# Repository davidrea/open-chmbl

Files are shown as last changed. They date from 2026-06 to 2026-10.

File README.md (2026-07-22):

# open-chmbl

In automotive engineering, the CHMBL is the "Center High-Mounted Brake Light" — this
repository is an **"Open-sourCe Helmet Mounted Brake Light"** for motorcyclists.

A battery-powered ~8″ LED bar worn on the rider's back — magnetically clamped to a
jacket or backpack — lights up when the motorcycle is braking. The reference bike
doesn't publish a brake-switch bit on its **CAN bus**, so braking is **inferred from
wheel-speed deceleration** read off the bus (via the Euro 5 diagnostic port,
**listen-only**) and sent wirelessly to the rider-side unit over **ESP-NOW**. Clutch
and gear/neutral context lets it hold the light through a stop and release it sensibly
when the bike pulls away — deriving deceleration from the bike's own CAN wheel-speed
(not an accelerometer) keeps it clear of the inertial-detection patents.

Two units, both ESP32-based:

- **[`transmitter/`](transmitter)** — bike-side; plugs into the diagnostic port,
  decodes CAN, broadcasts braking state.
- **[`brake_light/`](brake_light)** — rider-side; battery-powered LED bar (fabric
  mount this rev; helmet fitment deferred) that renders the state.

> ⚠️ Auxiliary device. It does **not** replace the bike's factory brake light, and
> helmet-mounted lighting is restricted in some places. Read
> **[`docs/safety-regulatory.md`](docs/safety-regulatory.md)** before building or
> riding.

## Start here

- **[`ARCHITECTURE.md`](ARCHITECTURE.md)** — system overview and design index.
- **[`docs/feature-functions.md`](docs/feature-functions.md)** — per-device capabilities.
- **[`docs/design/README.md`](docs/design/README.md)** — how we build it: design
  elements, implemented one at a time in isolation.
- [`docs/cli.md`](docs/cli.md) · [`docs/hardware.md`](docs/hardware.md) ·
  [`docs/firmware.md`](docs/firmware.md) · [`docs/protocol.md`](docs/protocol.md) ·
  [`docs/can-profiles.md`](docs/can-profiles.md) ·
  [`docs/safety-regulatory.md`](docs/safety-regulatory.md) ·
  [`docs/roadmap.md`](docs/roadmap.md)

Status: **architecture / design phase** (see the roadmap).

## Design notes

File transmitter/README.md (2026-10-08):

# Transmitter (bike-side)

Plugs into the motorcycle's diagnostic port, reads the CAN bus **listen-only**,
decodes brake/throttle/RPM/clutch via the active [bike profile](../docs/can-profiles.md),
runs the [braking state machine](../docs/firmware.md#braking-state-machine), and
broadcasts state to the [`brake_light`](../brake_light) over
[ESP-NOW](../docs/protocol.md).

- [`hardware/`](hardware) — reuses the [`logger/`](../logger) PCB (ESP32-S3); see
  [`hardware/README.md`](hardware/README.md) for pinout and BOM notes.
- [`software/`](software) — ESP32-S3 firmware for that board: TWAI listen-only,
  profile decode, the [braking state machine](../docs/design/de-09-brake-decel-logic.md)
  driving the light, and ESP-NOW TX. See
  [`software/README.md`](software/README.md).

See [`ARCHITECTURE.md`](../ARCHITECTURE.md) for the big picture and
[`docs/hardware.md`](../docs/hardware.md) for the parts sketch.

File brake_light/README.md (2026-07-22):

# Brake_light (rider-side)

Battery-powered ~8″ wide red LED bar worn on the rider's back — magnetically clamped
to a jacket or the top of a backpack between the shoulder blades (a steel strip or
washers inside the garment / pack completes the mount). Receives braking state from
the [`transmitter`](../transmitter) over [ESP-NOW](../docs/protocol.md) and renders
it on the bar with ambient-aware brightness, while managing its own 1S 18650 Li-ion
battery, USB-C charging, pairing, and [link-loss failsafe](../docs/protocol.md#4-failsafe--link-health).

Helmet fitment is **deferred** — the current form factor targets a thin, short-in-
the-vertical-axis, wide fabric-mounted bar so shell curvature and helmet-certification
questions don't gate the first build.

- [`hardware/`](hardware) — LED bar, 18650 + charging (chip-down), enclosure,
  magnetic fabric mount.
- [`software/`](software) — ESP32-C3 firmware (ESP-NOW RX + LED pattern engine).

⚠️ Mounting and battery safety are not optional — see
[`docs/safety-regulatory.md`](../docs/safety-regulatory.md). See
[`ARCHITECTURE.md`](../ARCHITECTURE.md) for the big picture.

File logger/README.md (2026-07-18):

# logger

A self-contained **CAN data logger** on a **custom ESP32-S3 PCB** with an onboard CAN
transceiver. It captures **all** bus traffic (no filtering) in **listen-only** mode
and writes it to the on-board microSD as **PCAN `.trc`** ASCII files that drop
straight into the project's offline decode/replay path (`python-can` + `cantools`,
see [`docs/can-profiles.md`](../docs/can-profiles.md)).

This is the **ride-logging rig** for design element
[**DE-07**](../docs/design/README.md) — a no-Linux ESP32 alternative to the Raspberry
Pi originally sketched for capturing wheel-speed and other in-motion signals. The
stationary bench captures are done separately with PCAN-USB + a laptop.

This board is also the base design the [`transmitter/`](../transmitter) reuses
(same PCB, connectors for the microSD and button/LED removed) — see
[`hardware/README.md §4`](hardware/README.md#4-shared-design-with-the-transmitter).

- [`hardware/`](hardware) — the custom ESP32-S3 PCB: schematics, connectors, power,
  and a known strapping-pin issue to check before relying on a board. See
  [`hardware/README.md`](hardware/README.md).
- [`software/`](software) — ESP-IDF firmware. **Currently still targets the retired
  ESP-WROVER-KIT bring-up hardware (`esp32`)**, not yet ported to the custom board
  above — see the status note in [`software/README.md`](software/README.md). Pins,
  wiring, the `.trc` format, and build/flash steps for the current target are
  documented there.

> Listen-only by default — the logger never ACKs or transmits, per the repo's
> [golden rule](../docs/can-profiles.md#1-golden-rule-listen-only). Power-loss and
> card-removal robustness are intentionally out of scope.

## Visualizing a log

Open [`tools/trc_viz.html`](../tools/trc_viz.html) directly in any modern browser,
then drag a logger `.trc` file onto the page (or use **Open trace**). It is one local
HTML file with no server, install, or network access required. The viewer decodes the
Triumph TR profile in-browser and provides live playback gauges, a zoomable timeline,
nearby raw-frame inspection, and live [DE-09 brake FSM](../docs/design/de-09-brake-decel-logic.md)
tuning. It does not upload or retain the trace.

For automated decode comparisons and the older native dashboard, the Python tools
remain available:

```sh
uv run tools/trc_viz.py logger/40mph_drive_cycle.trc --headless-check
```

[uv]: https://docs.astral.sh/uv/

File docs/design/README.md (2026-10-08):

# Design documents

How we get from capabilities to code: **feature-function lists → design documents →
isolated implementation → integration.** We deliberately avoid formal shall-statement
requirements; the [feature-function lists](../feature-functions.md) are the
capability baseline, and each **design element** below is a self-contained slice we
design and build **one at a time, in isolation**, exercised through the
[developer CLI](../cli.md).

---

## 1. Process

1. **Capabilities** live in [`feature-functions.md`](../feature-functions.md) (FFL IDs).
2. **Design elements** (this directory) each take a small set of FFL IDs and work them
   into a buildable design: components, I/O, firmware tasks, and the CLI hooks that let
   us test the element alone.
3. **Implement one element at a time.** Inputs at the element's boundary are **faked**
   via the CLI; outputs are **viewed** via the CLI. The element is "done" when its FFL
   IDs are demonstrable in isolation.
4. **Integrate** elements once each is independently proven.

Cross-cutting design context already in progress lives one level up:
[`hardware.md`](../hardware.md), [`firmware.md`](../firmware.md),
[`protocol.md`](../protocol.md), [`can-profiles.md`](../can-profiles.md), and the
[`led-brightness-benchmark.md`](../led-brightness-benchmark.md) sizing study (feeds DE-04
and DE-02). Design elements here reference those rather than repeating them.

---

## 2. Design-document template

Every `de-*.md` follows this structure:

1. **Scope & isolation boundary** — what's in, what's out, and *what is faked at the
   edges* to test it alone.
2. **FFL traceability** — the [feature-function](../feature-functions.md) IDs this
   element realizes.
3. **Component selection** — hardware parts and/or software libraries this element
   depends on, with rationale (defer to [`hardware.md`](../hardware.md) for shared parts).
4. **I/O assignments & configuration** — pins, peripherals, registers, bit rates,
   timings, message layouts.
5. **Firmware module/task decomposition** — tasks, queues, shared state, rates,
   ownership; the pure (host-testable) vs. platform parts.
6. **CLI hooks** — the [CLI](../cli.md) commands used to fake inputs / view outputs for
   isolation testing.
7. **Isolation acceptance** — what we demonstrate, via the CLI, to call it done.
8. **Open items.**

---

## 3. Design elements (build order)

Ordered by dependency and the agreed sequence (CLI first so everything else is
testable in isolation; CAN-dependent elements last, after captures exist). Status:
🔲 not started · 🟡 in design · 🟢 implemented.

| ID | Element | Device(s) | Realizes (FFL) | Depends on | Status |
|----|---|---|---|---|---|
| **DE-00** | [CLI / shell framework](../cli.md) | both | TX-CLI-*, BL-CLI-* | — | 🟡 |
| **DE-01** | [ESP-NOW link](de-01-espnow-link.md) | both | TX-NET-*, BL-NET-* | DE-00 | 🟢 |
| **DE-02** | [Auto-brightness](de-02-auto-brightness.md) | brake_light | BL-BRT-* | DE-00 | 🔲 |
| **DE-03** | [Link-loss failsafe](de-03-link-loss-failsafe.md) | brake_light | BL-FS-* | DE-00, DE-01 | 🟡 |
| **DE-04** | [LED render & bar driver](de-04-led-render.md) | brake_light | BL-RND-*, BL-LED-* | DE-00 | 🟡 |
| **DE-05** | Battery & charge management | brake_light | BL-PWR-* | DE-00 | 🔲 |
| **DE-06** | TX power / sleep / wake | transmitter | TX-PWR-* | DE-00 | 🔲 |
| **DE-07** | CAN capture & offline analysis — bench (PCAN-USB) + [ride logger](../../logger/) (custom ESP32-S3 PCB) | host + [`logger/`](../../logger/) | (enables TX-DEC) | — | 🟡 |
| **DE-08** | [Embedded CAN decode](de-08-can-decode.md) | transmitter | TX-CAN-*, TX-DEC-* | DE-00, DE-07 | 🔲 |
| **DE-09** | [Braking state machine](de-09-brake-decel-logic.md) | transmitter | TX-SM-* | DE-00, DE-08 | 🟢 |
| **DE-10** | [Status-indicator LED](de-10-status-indicator.md) | brake_light | BL-IND-* | DE-00 | 🔲 |

DE-05…DE-06 don't have stub docs yet; they get one when scheduled. DE-07 is the
bench/ride reverse-engineering captured in [`can-profiles.md`](../can-profiles.md); the
**ride-logging half is now a real device** — a self-contained logger under
[`logger/`](../../logger/) (firmware implemented, now with a
[custom ESP32-S3 PCB](../../logger/hardware/README.md) — firmware port from the
original ESP-WROVER-KIT bring-up hardware pending) that replaces the Raspberry Pi
rig, while the stationary bench captures stay on PCAN-USB + a laptop.

This table is the single source of truth for "what's the next isolated piece."

---

## 4. Future-state explorations

Directions we want on record but have **not** committed to the build order above.
They live in [`explorations/`](explorations/README.md) and get promoted to a
`de-*` element (with FFL traceability and an isolation test) only when scheduled:

- [Magnetic mounting](explorations/mounting-magnetic.md) — garment/backpack shoulder
  mount and interchangeable VHB-on-helmet steel targets, both using magnets for a
  built-in shear release.

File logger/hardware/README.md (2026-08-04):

# Logger — hardware

Custom PCB (KiCad, [`logger.kicad_pro`](logger.kicad_pro)) that replaced the original
ESP-WROVER-KIT bring-up rig. Self-powered from the bike's 12 V or from USB-C, decodes
nothing on-board — it just timestamps and records **all** CAN traffic to a microSD card.
See [`../README.md`](../README.md) for the device-level description and
[`../software/README.md`](../software/README.md) for firmware status.

This board is also the **base design for the [`transmitter/`](../../transmitter)**
bike-side unit — see [§4](#4-shared-design-with-the-transmitter).

## 1. MCU: ESP32-S3-WROOM-1-N4

**ESP32-S3**, not the ESP32-C3 used elsewhere in this project (`brake_light/`, and
the transmitter's earlier sketch — see [`docs/hardware.md`](../../docs/hardware.md)).
The reason is the **microSD interface**: this design uses the SoC's native **SDMMC
host peripheral** (full 4-bit bus — `CLK`/`CMD`/`DAT0`–`DAT3`, see §3.4) for the
throughput a listen-only, no-filtering CAN capture needs. **The ESP32-C3 doesn't have
an SDMMC host peripheral** — only SPI — so it was not an option for this board. The
C3 stays the right choice for `brake_light/`, which has no SD card.

`-N4` = 4 MB flash, **no PSRAM**. (The retired ESP-WROVER-KIT target had 4 MB of
PSRAM the firmware currently depends on — `CONFIG_SPIRAM=y` — see the note in
[`../software/README.md`](../software/README.md).)

## 2. Power

```
 J3 pin 3 (+12 V, bike) ──▶ D4 (Schottky, reverse-pol.) ─┐
                                                          ├─▶ +5VD rail ─▶ U4 (TPS62172
 J2 (USB-C VBUS, 5 V)   ──▶ U3 (USBLC6-2P6 ESD) ─────────┘              buck) ─▶ +3V3
```

- **D4** (`20CJQ060`, Schottky) diode-ORs the bike's 12 V input against USB-C VBUS
  onto a shared **+5VD** rail, so the board can be bench-powered/flashed over USB-C
  without the bike connected, and the diode blocks backfeed onto the bike harness.
- **U4** (`TPS62172`, buck) steps +5VD down to **+3V3**, which powers the ESP32-S3,
  the CAN transceiver, and the microSD card.
- **D3** (`SM24CANB-02HTG`, dual TVS) sits right at J3 protecting CAN-H/CAN-L from
  bus transients.

There is no automotive load-dump-rated buck or a dedicated reverse-polarity FET here
(that was the original `docs/hardware.md` sketch) — this rev uses a Schottky diode for
reverse-polarity protection and a standard (not automotive-grade) buck. Revisit before
this board goes on a bike full-time; fine for bench/ride-logging use.

## 3. Connectors

| Ref | Type | Function |
|-----|---|---|
| **J2** | USB-C receptacle | Power, flash, and console. **Native USB** — D+/D- wired directly to the ESP32-S3 (no USB-UART bridge chip). CC1/CC2 have 5.1 kΩ pull-downs (UFP power-sink detection). ESD-protected by U3 (`USBLC6-2P6`). |
| **J3** | JST-PH, 5-pin | Bike harness. Pin 1 **CAN-L**, pin 2 **CAN-H**, pin 3 **+12 V**, pin 4 **GND**, pin 5 **spare/unconnected**. TVS-protected at the connector (D3). |
| **J4** | JST-PH, 4-pin | Button/LED breakout. Pin 1 **GND**, pin 2 **LED drive** (through Q1, a low-side `2N7002K` switch), pin 3 **button input** (`BTN_SIG`, pulled up to 3V3, active-low), pin 4 **+3V3**. Both signal pins are TVS-protected (D1/D2, `PTVS3V3D1BALYL`) since this connector feeds an external panel-mount switch/LED on flying leads. |
| **J5** | microSD (Molex 104031-0811) | Full SDMMC **4-bit** bus (`CLK`, `CMD`, `DAT0`–`DAT3`) + card-detect (`DET_A`, pulled up) + 3V3/GND, wired straight to the ESP32-S3's SDMMC host peripheral. |

### 3.1 CAN transceiver

**U2 (`TCAN330`)**, 3.3 V logic — TXD/RXD to the ESP32-S3, plus its **silent-mode
(`S`) pin** wired to a GPIO so firmware can force RX-only operation in hardware, not
just in software. This pin was moved to a non-strapping GPIO to fix an earlier
strapping-pin conflict — see [§5](#5-resolved--can-silent-pin-moved-off-strapping-pin-gpio45).

### 3.2 microSD (J5)

Sized for a real ride-logging device: full 4-bit SDMMC, not the slower 1-bit/SPI
fallback. This is the peripheral that dictated the ESP32-S3 (§1).

### 3.3 Button/LED (J4)

Optional external start/stop button + status LED on flying leads (the onboard `SW1`/
`SW2` push-button footprints are DNI placeholders for a bench BOOT/EN header, not the
operator control). `Q1` (`2N7002K`) is a low-side switch for driving an LED through
J4 pin 2; `R4` is the current-limit resistor.

## 4. Shared design with the transmitter

The `transmitter/` bike-side unit reuses this exact board with **J4** (button/LED)
and **J5** (microSD) left unpopulated — the transmitter needs neither a card slot nor
a physical button/LED breakout. See
[`transmitter/hardware/README.md`](../../transmitter/hardware/README.md) and
[`docs/hardware.md §1`](../../docs/hardware.md#1-transmitter-bike-side).

## 5. Resolved — CAN silent pin moved off strapping pin (`GPIO45`)

An earlier rev routed the CAN transceiver's silent-mode pin (`U2` pin 8) to
**`GPIO45`**, one of the ESP32-S3's strapping pins — it selects the SPI-flash/PSRAM
supply voltage at reset (low = internal 3.3 V regulator, correct for this module;
high = expects an externally-supplied 1.8 V rail). **`R16`** pulls the `S` pin up to
3V3 to default the transceiver to **silent mode before firmware runs** (the right
failsafe for a listen-only device), but with `S` on `GPIO45` that pull-up also drove
the strapping pin high at boot — the same class of bug already hit once on this
project's bench boards (GPIO8 vs. the SPI-flash bus — see the blink-LED note) and a
known cause of ESP32-S3 boards that won't boot / report flash read errors.

**This is fixed in the current schematic:** the `S` pin is now on **`GPIO35`** (a
non-strapping GPIO, free on the `-N4` module since it has no PSRAM), and `R16` pulls
`GPIO35` up — keeping the default-silent failsafe without touching any strap.
`GPIO45` is left **unconnected**, so its internal pull-down selects the 3.3 V flash
supply as intended. The two other straps are clean too: `IO0` is the boot button
(internal pull-up) and `GPIO46` is unconnected. Still worth a bring-up confirmation
that `GPIO45` is unstuffed and boot is repeatable — see
[`BRINGUP.md §4`](BRINGUP.md#4-gpio--strapping-verification).

## 6. Fabrication / BOM

KiCad project only — `bom.csv`, `positions.csv`, `netlist.ipc`, and the JLC
export zip under `production/` are regenerated locally by the KiCad Fabrication
Toolkit plugin and are **gitignored**, not committed. Re-export from
[`logger.kicad_pcb`](logger.kicad_pcb) / [`logger.kicad_sch`](logger.kicad_sch) as
needed.

Key parts: `U1` ESP32-S3-WROOM-1-N4, `U2` TCAN330, `U4` TPS62172, `U3` USBLC6-2P6,
`D3` SM24CANB-02HTG, `D4` 20CJQ060.

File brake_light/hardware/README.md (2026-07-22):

# Brake_light — hardware

Rider-side electronics. See [`docs/hardware.md §2`](../../docs/hardware.md#2-brake_light-rider-side)
for the block diagram and parts sketch.

Key constraints:
- **Bare ESP32-C3 module** (ESP32-C3-WROOM-02 baseline) + **chip-down** LiIon
  charger, DC-DC, and LED driver. Moved off the integrated dev-board path (previously
  scoped in the removed `§2.1` module survey) to unlock the thin/wide form factor
  below — see [`docs/hardware.md §2.1`](../../docs/hardware.md#21-parts-direction-bare-module--chip-down).
- **~8″ wide red LED bar** (620–630 nm mid-power) driven from a boost constant-current
  driver (TI **LM3410** baseline; upgrade parts noted in de-04). One series string of
  ~8 emitters — split into parallel strings if the emitter count outruns the driver's
  V<sub>out</sub> ceiling. Series-string + boost topology set in
  [`docs/design/de-04`](../../docs/design/de-04-led-render.md).
- **Ambient-light auto-dimming** (safety requirement — no blinding at night).
- **Status-indicator LED** — **discrete WS2812B** (2020 / Mini) chip-down, **separate
  from the bar** — for status/fault by color + blink code
  ([`docs/design/de-10`](../../docs/design/de-10-status-indicator.md)). No longer
  free-riding on a module's onboard RGB (we're on a bare module now).
- **Battery: 1S 18650 Li-ion, protected cell** + USB-C charging with **load sharing**
  (MCP73871 chip-down baseline). 18650 chosen over pouch/LiPo because pouch cells
  need mechanical compression the thin enclosure can't provide; protected cell means
  the load-share IC doesn't have to double as cell protection.
- **Form factor: thin, short-in-vertical (viewed from the rear), wide.** The ~8″ LED
  bar sets the width; the 18650's ~18 mm diameter sets the enclosure-thickness floor.
- **Mount: magnetic to jacket / backpack fabric.** Magnets live in the light
  assembly; a thin steel strip or washers sit inside the garment or pack so the
  fabric is sandwiched between them. This is the [garment / backpack shoulder
  mount](../../docs/design/explorations/mounting-magnetic.md#exploration-a--garment--backpack-shoulder-mount)
  exploration promoted to the current baseline; helmet fitment and cross-form
  interchangeability are **deferred**.
- Sized for a full-day runtime target — with a ~3000 mAh 18650 the runtime budget
  roughly doubles the earlier 1500 mAh LiPo worked example (see hardware doc).
- Sealed, IP65+ enclosure.

⚠️ Mounting + Li-ion safety are mandatory reading: [`docs/safety-regulatory.md`](../../docs/safety-regulatory.md).

_Schematics, BOM, enclosure, and mount files to be added (Phase 4)._

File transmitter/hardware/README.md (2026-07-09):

# Transmitter — hardware

Bike-side electronics. See [`docs/hardware.md §1`](../../docs/hardware.md#1-transmitter-bike-side)
for the block diagram and parts sketch.

**Hardware plan: this board is the [`logger/`](../../logger) PCB**, reused with the
microSD slot (J5) and button/LED breakout (J4) left unpopulated — the transmitter
needs neither. No separate transmitter schematic exists; the logger's is the source
of truth. See [`logger/hardware/README.md`](../../logger/hardware/README.md) for the
schematic, connector pinout (J2 USB-C, J3 bike harness), and BOM notes, and
**[§5 there](../../logger/hardware/README.md#5-known-issue--gpio45s-pin-conflicts-with-a-boot-strap)**
for an open strapping-pin issue to check before building a board off this design.

As reused:
- **ESP32-S3-WROOM-1** + **TCAN330** CAN transceiver (3.3 V), silent-mode pin wired
  to a GPIO for a hardware-level listen-only default.
- Diode-ORed 12 V (bike) / USB-C VBUS power into a TPS62172 buck (12 V → 3.3 V).
  **Not** automotive load-dump-rated in this rev — reverse-polarity protection is a
  Schottky diode, not a FET; revisit before full-time bike use.
- **Listen-only** CAN — never ACK or transmit on the bus.
- J3 (bike-side connector, JST-PH 5-pin): CAN-L, CAN-H, +12 V, GND, spare.

Not yet on this board (deltas from the shared logger design, tracked for Phase 4):
- Deep-sleep / load-shed when the bike is off (< 1 mA parked) — needs an ignition
  sense the logger board doesn't have.
- Sealed, IP65+, vibration- and heat-tolerant enclosure.

Reference bike connector ([Triumph Speed 400 / Scrambler 400 X / Street Triple 765](../../docs/can-profiles.md#5-reference-target--triumph-speed-400-tr-series-platform)):
**red 6-pin OBD2** under the seat, carrying CAN-H/CAN-L + K-line. Use a 6-pin →
16-pin adapter, or wire a mating 6-pin plug directly into J3. **Confirm exact pin
positions and bus bit rate by probing before connecting.**

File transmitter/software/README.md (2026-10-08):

# Transmitter — software

Bike-side firmware for the **logger PCB** ([`logger/hardware/`](../../logger/hardware) —
ESP32-S3-WROOM-1-N4, onboard TCAN330 transceiver, **ESP-IDF**). There is no separate
transmitter board: the transmitter *is* the logger board with the microSD slot (J5)
and, in the final build, the remote pod connector (J4) left unpopulated — see
[`docs/hardware.md §1`](../../docs/hardware.md#1-transmitter-bike-side) and
[`docs/firmware.md §1`](../../docs/firmware.md#1-transmitter-firmware-bike-side).

> **Target:** `esp32s3`. The earlier `esp32c3` / classic-`esp32` dev boards are **no
> longer supported** — the pin map, the native-USB console and the three-LED indicator
> are all specific to this board, exactly as for the logger firmware. For the dev-board
> version, see the history before the port.

Responsibilities:
- **TWAI (CAN 2.0)** in **listen-only** mode, filtered to the
  [bike profile](../../docs/can-profiles.md) IDs, with the transceiver held silent in
  hardware (below).
- Decode `wheel_speed`, `throttle_pct`, `rpm`, `clutch_pulled`, `gear`/`neutral`
  ([DE-08](../../docs/design/de-08-can-decode.md)) and derive acceleration from wheel
  speed. The reference bus carries **no brake-switch bit**.
- Run the [braking state machine](../../docs/design/de-09-brake-decel-logic.md) at
  50 Hz and drive the **brake-light output**.
- Broadcast the resulting state over [ESP-NOW](../../docs/protocol.md) at 20–50 Hz.

## The brake light, right now

The state machine's output drives **IO18** — on a logger that is the operator's pod LED
on J4; here it is the brake light. With J4 populated on the bench board, **that pod LED
is the brake light under test**: it lights exactly when the FSM says BRAKING or STOPPED,
with no pattern of its own, so what you see on the bench is the decision the radio will
eventually carry. The same state already goes out over ESP-NOW (`net show`), so pointing
it at a real rider-side light later changes nothing in this firmware.

## Silent mode is enforced in hardware

`R16` (10K) pulls the TCAN330's **S** pin up to 3V3, and **S high = silent**: the
transceiver receives but its driver is disabled, so it cannot put a dominant bit — not
even an ACK — onto the bus.

That pin is **GPIO35**, which is **U1 pin 28**. (Easy to transpose; the netlist table in
[`logger/hardware/BRINGUP.md §0`](../../logger/hardware/BRINGUP.md) is authoritative.)

The firmware configures GPIO35 as a **high-impedance input with both internal pulls
disabled**, and never drives it, so silence is the power-on default and the failure-safe
state: it holds through reset, through boot before `app_main` runs, and through a
firmware crash. The internal pull-up is left off deliberately — it would hold S high even
if `R16` were missing, hiding exactly the board fault that would let the transmitter talk
on a live bus. At boot the pin is read back; a low reading is logged loudly and lights
the fault lamp. The TWAI controller is **also** held in listen-only mode. Both halves of
the golden rule — never disturb a live vehicle bus — are in force, and neither depends
on the other. Identical treatment to the logger firmware on this board.

## Indicators

| LED | GPIO | Shows |
|-----|:----:|---|
| External indicator (J4 pin2, the pod LED) | **IO18** | **the brake light** — on = BRAKING or STOPPED |
| **D5** green (onboard) | **IO2** | bus liveness: heartbeat → no CAN traffic · **inverted** heartbeat → traffic present |
| **D6** red (onboard) | **IO1** | fault lamp: **2 Hz, 50% duty** if the silent pin reads low or TWAI fails to start; dark otherwise |

"Heartbeat" is a double thump (lub-dub) on a 2 s period; **inverted heartbeat** is that
waveform negated — mostly lit, two brief dropouts. Timings match the logger's indicator,
so the same board means the same thing whichever image is flashed.

## Hardware / wiring

As-built pin map, from the exported KiCad netlist — the same table as
[`logger/hardware/BRINGUP.md §0`](../../logger/hardware/BRINGUP.md). Do **not** take pin
numbers from the older `logger_sch_revA.pdf` or from `logger/hardware/README.md`; both
are stale.

| Signal | GPIO | Notes |
|---|:----:|---|
| CAN TXD | **IO21** | → U2 (TCAN330) pin1; `R15` pull-up |
| CAN RXD | **IO47** | ← U2 pin4 |
| CAN S (silent) | **IO35** | U1 **pin 28**; `R16` pull-up → **hi-z, defaults silent** |
| Brake-light output | **IO18** | Q1 gate via `R3`, low-side to J4 pin2 |
| Status LED D5 (green) | **IO2** | via `R20`, active-high |
| Status LED D6 (red) | **IO1** | via `R21`, active-high |

All of these are configurable in `menuconfig` (*Transmitter configuration*). The logger's
microSD pins (IO8–IO12, IO17, IO48) and its start/stop button (IO6) are **untouched** by
this firmware — the transmitter populates neither.

> The DE-09 tunables are deliberately **not** Kconfig options: they are floats that get
> swept, not build-time choices. They default to the calibrated values in
> `brake_fsm.h` and are adjustable live with `state tune` (below), which is the same
> loop [`tools/trc_viz.html`](../../tools/trc_viz.html) offers offline.

## Structure

```
software/
├── CMakeLists.txt          top-level ESP-IDF project
├── sdkconfig.defaults      committed defaults (generated sdkconfig is gitignored)
├── main/
│   ├── CMakeLists.txt
│   ├── Kconfig.projbuild    pin map, CLI toggle, ESP-NOW channel/rate
│   ├── main.c               app_main: indicators, link, CAN, FSM, console
│   ├── bike_profile*.[ch]   generated CAN profile data (tools/gen_profile.py)
│   ├── can_decode.[ch]      pure decode + derived acceleration (host-testable)
│   ├── can_rx.[ch]          TWAI listen-only RX task, silent pin, signal snapshot
│   ├── brake_fsm.[ch]       DE-09 state machine — pure, host-testable
│   ├── brake_ctl.[ch]       50 Hz tick, brake-light output, force override, tunables
│   ├── status_led.[ch]      the three LEDs
│   ├── pairing.[ch], net.[ch]   ESP-NOW peer + heartbeat (DE-01)
│   ├── console.c            REPL bootstrap (native USB Serial/JTAG)
│   └── cmd_*.c              one file per console command
└── test_host/              host harnesses for the pure cores (no ESP-IDF)
```

`can_decode.c`, `brake_fsm.c` and the profile data are deliberately
platform-independent (no IDF headers) so they can be host-tested, per
[`docs/firmware.md §4`](../../docs/firmware.md#4-build--toolchain).

## Console

Over the S3's native USB Serial/JTAG (`idf.py monitor`) — this board has no UART bridge,
so that is the only console it has. Type `help` at the `chmbl>` prompt.

| Command | Purpose |
|---|---|
| `help` | List commands. |
| `id` | Chip unique ID (base MAC), model/revision, IDF version. |
| `state [show]` | FSM state, the inputs it saw, its timers, and the emitted output state. |
| `state force off\|brake\|auto` | Override the emitted state, or hand it back to the FSM. |
| `state tune [<name> <value>]` | List or set a DE-09 tunable, live. |
| `sig show \| set \| ramp \| source` | Inspect or fake decoded signals — `sig source fake` then `sig ramp wheel -12` drives a synthetic stop straight through the real FSM. |
| `can show \| can replay decel` | CAN RX diagnostics; replay a synthetic vector through an offline decoder. |
| `pair …`, `net …` | ESP-NOW peer and heartbeat (DE-01). |

Bench recipe for the light, no bus required:

```
sig source fake
sig set gear 3
sig set clutch 0
sig ramp wheel -12 until 0     # a firm stop: light comes on, stays on through the stop
state show
```

## Build

Requires [ESP-IDF](https://docs.espressif.com/projects/esp-idf/en/stable/esp32s3/get-started/)
(v5.3+). With the IDF environment sourced:

```bash
cd transmitter/software
idf.py set-target esp32s3
idf.py menuconfig      # optional: pins, ESP-NOW channel/rate
idf.py build
idf.py flash monitor   # console rides native USB — no UART bridge on this board
```

> **Build for 4 MB.** U1 is an `ESP32-S3-WROOM-1-N4`: 4 MB flash, **no PSRAM**
> (`CONFIG_SPIRAM` must be *absent*, not merely `=n`). Both are set in
> `sdkconfig.defaults`. Build at 8 MB by mistake and the app boot-loops before
> `app_main` — see [`BRINGUP.md §3`](../../logger/hardware/BRINGUP.md) for the exact
> signature and why the bootloader's `SPI Flash Size` line is not evidence.

## Host tests

`test_host/` builds two harnesses against the same sources the firmware compiles, with
no ESP-IDF involved:

```bash
cmake -S transmitter/software/test_host -B transmitter/software/test_host/build
cmake --build transmitter/software/test_host/build
pip install -r tools/requirements.txt

python3 tools/golden_check.py    # DE-08: C decoder vs python-cantools
python3 tools/fsm_check.py       # DE-09: C state machine vs the reference
```

`fsm_check.py` replays a ride capture through the firmware's FSM and through
[`tools/trc_viz.py`](../../tools/trc_viz.py) — the Python twin of the in-browser bench
the tunables were calibrated on — and asserts they produce the **same state at every
tick**. Retune the bench without porting the change (or "clean up" the firmware and alter
its behaviour) and this fails. Both run in CI on every push.

## CI

[`.github/workflows/firmware-build.yml`](../../.github/workflows/firmware-build.yml)
builds this project with the real ESP-IDF toolchain (`espressif/esp-idf-ci-action`,
target `esp32s3`) on every push/PR that touches the firmware, and runs both host tests
above.

_Raw CAN capture logs go under `captures/`._

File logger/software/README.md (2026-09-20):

# logger — software

CAN data-logger firmware for the **custom logger PCB** ([`../hardware/`](../hardware) —
ESP32-S3-WROOM-1-N4, onboard TCAN330 transceiver, native SDMMC microSD, **ESP-IDF**).
Captures all CAN traffic, no filtering, and writes **PCAN `.trc` (v2.1)** files to the
microSD.

> **Target:** `esp32s3`. The retired ESP-WROVER-KIT (`esp32`) is **no longer
> supported** — the pin map, the native-USB console and the three-LED indicator are
> all specific to this board. For the WROVER-KIT version, see the history before the
> port.

Responsibilities:
- **TWAI (CAN 2.0)** in **listen-only** mode (Kconfig-selectable to normal/ACK), all
  IDs accepted — see [`docs/can-profiles.md`](../../docs/can-profiles.md).
- Timestamp every frame and write it to microSD in **PCAN `.trc`** format, compatible
  with PCAN-Explorer and `python-can`'s `TRCReader` (the offline path in
  [`can-profiles.md §5`](../../docs/can-profiles.md#3-sniffing-methodology)).
- **One pushbutton** start/stop on **IO6**: each **start** opens a new `N.trc` (N an
  increasing integer), each **stop** closes it. Debounced in software via the
  `iot_button` component.
- Gate all microSD work on **card presence (DET_A, IO8)** — no mount without a card,
  no recording without a mount, and a card pulled mid-capture aborts cleanly instead
  of wedging the writer.
- Emit a **running operations log** over the native-USB console — view with
  `idf.py monitor`. At boot that includes the CAN silent-pin readback, whether a card
  is **detected**, the **mount result**, and a **listing of every file on the card**
  with sizes.
- Drive the **three status LEDs** (see below).

## Silent mode is enforced in hardware

`R16` (10K) pulls the TCAN330's **S** pin up to 3V3, and **S high = silent**: the
transceiver receives but its driver is disabled, so it cannot put a dominant bit —
not even an ACK — onto the bus.

That pin is **GPIO35**, which is **U1 pin 28**. (Easy to transpose; the netlist table
in [`../hardware/BRINGUP.md §0`](../hardware/BRINGUP.md) is authoritative.)

The firmware configures GPIO35 as a **high-impedance input with both internal pulls
disabled**, and never drives it. So silence is the power-on default and the
failure-safe state: it holds through reset, through boot before `app_main` runs, and
through a firmware crash. The internal pull-up is left off deliberately — it would
hold S high even if `R16` were missing, hiding exactly the board fault that would let
the logger transmit onto a live bus. At boot the firmware reads the pin back and
shouts if it is anything but high.

The TWAI controller is **also** held in listen-only mode. Both halves of the golden
rule — never disturb a live vehicle bus — are in force, and neither depends on the
other.

## Status LEDs

"Heartbeat" is a double thump (lub-dub) on a 2 s period; **inverted heartbeat** is
that same waveform negated — mostly lit, two brief dropouts. The pair reads at a
glance and neither can be confused with the error blink.

| LED | GPIO | Shows | Patterns |
|-----|:----:|---|---|
| External indicator (operator's pod, J4, alongside the button) | **IO18** | logger state | idle → heartbeat · recording → **inverted** heartbeat · error → **2 Hz, 50% duty** |
| **D5** green (onboard) | **IO2** | bus liveness | no CAN traffic → heartbeat · CAN traffic present → **inverted** heartbeat |
| **D6** red (onboard) | **IO1** | card activity | brief flash per microSD write · error → **2 Hz, 50% duty** |

Notes:
- D5 is driven by the TWAI controller, which **runs continuously** — not only while
  recording. Bus liveness has to be answerable *before* you press record; walking back
  to the bike to discover the harness was unplugged is the failure this prevents.
  Frames received while idle are counted for the indicator and discarded.
- D6's flash tracks *actual card writes*, not frames. The `.trc` stream is fully
  buffered (32 KB), so frames do not each hit the card; the firmware pulses D6 once
  per buffer's worth. Flashing per frame would report the wrong thing and, at
  ~1500 frames/s, would peg D6 solid — indistinguishable from a fault.
- D5 stays independent of the error state, so "no card" and "no CAN" remain
  distinguishable without reaching for the console.

## Hardware / wiring

As-built pin map, from the exported KiCad netlist — the same table as
[`../hardware/BRINGUP.md §0`](../hardware/BRINGUP.md). Do **not** take pin numbers
from the older `logger_sch_revA.pdf` or from `hardware/README.md`; both are stale.

| Signal | GPIO | Notes |
|---|:----:|---|
| Start/stop button (BTN_SIG) | **IO6** | J4 pin3; `R5` pull-up, **active-low**, debounced in software |
| CAN TXD | **IO21** | → U2 (TCAN330) pin1; `R15` pull-up |
| CAN RXD | **IO47** | ← U2 pin4 |
| CAN S (silent) | **IO35** | U1 **pin 28**; `R16` pull-up → **hi-z, defaults silent** |
| SD CLK / CMD | **IO9** / **IO10** | J5 pin5 (via `R12`) / pin3 |
| SD DAT0–3 | **IO48 / IO17 / IO12 / IO11** | J5 pin7 / 8 / 1 / 2 |
| SD card-detect (DET_A) | **IO8** | J5 pin10; `R17` pull-up, **active-low** |
| External indicator LED | **IO18** | Q1 gate via `R3`, low-side to J4 pin2 |
| Status LED D5 (green) | **IO2** | via `R20`, active-high |
| Status LED D6 (red) | **IO1** | via `R21`, active-high |

All of these, plus bit rate, listen-only and the SDMMC bus width, are configurable in
`menuconfig` (*CAN logger configuration*, *microSD (SDMMC)*, *Status indicators*).
Defaults: **500 kbit/s**, **listen-only**, **4-bit SDMMC**.

> **Internal pull-ups are deliberately left disabled** on BTN_SIG, DET_A and the CAN
> silent pin, and `SDMMC_SLOT_FLAG_INTERNAL_PULLUP` is not set on the SD bus. The
> board carries proper external pull-ups (`R5`, `R17`, `R16`, `R7`–`R11`); an internal
> pull would read correct even with one of those unstuffed, turning a real board fault
> into a false pass. Same reasoning as [`BRINGUP.md §4.5`](../hardware/BRINGUP.md).

> **Bring-up aid:** *microSD → SDMMC bus width* selects 1-bit or 4-bit. `BRINGUP.md`
> §6.2 mounts 1-bit first, then §6.3 moves to 4-bit; the boot log reports the width
> actually negotiated, so the two are distinguishable.

## PCAN `.trc` format

Files are `N.trc` (`1.trc`, `2.trc`, …) at the card root, written as PCAN trace
**version 2.1**:

```
;$FILEVERSION=2.1
;$STARTTIME=43831.0000000
;$COLUMNS=N,O,T,B,I,d,R,L,D
...
      1        0.000 DT  1      123 Rx  -  8    DE AD BE EF 00 11 22 33
```

Columns: message number, time offset (ms from the first frame), type (`DT`/`RR`), bus,
ID (hex; extended IDs are 8 digits), direction (always `Rx`), reserved, DLC, data.

> **No on-board RTC** → `$STARTTIME` is a fixed placeholder; only the **relative time
> offsets** between frames are meaningful. That is exactly what offline decode/replay
> uses, so captures analyse correctly.

## Structure

```
software/
├── CMakeLists.txt          top-level ESP-IDF project
├── sdkconfig.defaults      committed defaults (generated sdkconfig is gitignored)
├── bringup/                standalone bring-up scratch apps + reset soak script
└── main/
    ├── CMakeLists.txt
    ├── idf_component.yml    espressif/button (iot_button); rest is ESP-IDF
    ├── Kconfig.projbuild    pin map, bit rate, listen-only, queue depth, SD width, LEDs
    ├── trc_format.[ch]      pure PCAN .trc formatting (host-testable)
    ├── ui_log.[ch]          operations log to the console
    ├── status_led.[ch]      three-LED indicator (state / bus / card)
    └── logger_main.c        app_main: TWAI, microSD, button, RX + writer + card-detect tasks
```

`trc_format` is deliberately platform-independent (no IDF headers) so it can be
host-unit-tested, per [`docs/firmware.md §4`](../../docs/firmware.md#4-build--toolchain).

## Build

Requires [ESP-IDF](https://docs.espressif.com/projects/esp-idf/en/stable/esp32s3/get-started/)
(v5.2+). With the IDF environment sourced:

```bash
cd logger/software
idf.py set-target esp32s3
idf.py menuconfig      # optional: pins, bit rate, mode, SD bus width
idf.py build
idf.py flash monitor   # console rides native USB — no UART bridge on this board
```

The `espressif/button` component is pulled automatically by the component manager on
first build.

> **Build for 4 MB.** U1 is an `ESP32-S3-WROOM-1-N4`: 4 MB flash, **no PSRAM**
> (`CONFIG_SPIRAM` must be *absent*, not merely `=n`). Both are set in
> `sdkconfig.defaults`. Build at 8 MB by mistake and the app boot-loops before
> `app_main` — see [`BRINGUP.md §3`](../hardware/BRINGUP.md) for the exact signature
> and why the bootloader's `SPI Flash Size` line is not evidence.

## CI

[`.github/workflows/firmware-build.yml`](../../.github/workflows/firmware-build.yml)
builds this project with the real ESP-IDF toolchain (`espressif/esp-idf-ci-action`,
target `esp32s3`) on every push/PR that touches the firmware, confirming it compiles.

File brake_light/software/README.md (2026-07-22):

# Brake_light — software

Rider-side firmware (ESP32-C3, ESP-IDF). See
[`docs/firmware.md §2`](../../docs/firmware.md#2-brake_light-firmware-rider-side).

Responsibilities:
- Receive `chmbl_msg_t` over [ESP-NOW](../../docs/protocol.md) (encrypted, pre-paired peer).
- Validate sequence / drop stale packets.
- Render state via the [LED pattern engine](../../docs/firmware.md#pattern-engine-suggested-mapping) (60 Hz), steady / no strobing.
- **Ambient-light dimming**, battery monitoring + low-battery warning.
- **Link-loss failsafe**: distinct indication, never silently dark, never a latched fake brake.
- Button UI: power, pairing, brightness cap.

## Status

Bootstrapped ESP-IDF project — now hosting the first slice of the **developer
CLI** (design element [DE-00](../../docs/design/README.md)). The real helmet-side
firmware (ESP-NOW RX + LED pattern engine) lands on top of this; the console
exists so each later element can be faked/observed in isolation on the bench.

```
software/
├── CMakeLists.txt          top-level ESP-IDF project
├── sdkconfig.defaults      committed defaults (common)
├── sdkconfig.defaults.esp32c3   product target — USB Serial/JTAG console
├── sdkconfig.defaults.esp32     interim dev hardware — UART console
└── main/
    ├── CMakeLists.txt
    ├── Kconfig.projbuild    CHMBL_CLI / CHMBL_LIGHT_GPIO options
    ├── console.h
    ├── main.c              app_main: start the console
    ├── console.c           REPL bootstrap (USB Serial/JTAG, UART fallback)
    ├── cmd_system.c        `id`    — chip unique ID (base MAC) + chip info
    └── cmd_light.c         `light` — drive the stand-in brake-light GPIO
```

### Targets & console transport

The firmware builds for two targets; pick one with `idf.py set-target`. The
console code is identical — only the transport (chosen by the per-target
`sdkconfig.defaults.<target>`) and the default light GPIO differ.

| Target | Status | Console transport | Connect | JTAG on same cable |
|---|---|---|---|---|
| `esp32c3` | product target | built-in **USB Serial/JTAG** (native USB GPIO18/19) | `/dev/ttyACM*`, any baud | yes |
| `esp32` | interim dev hardware | **UART0** (GPIO1 TX / GPIO3 RX) via onboard USB-UART bridge | `/dev/ttyUSB*`, 115200 | no (needs external probe) |

On the C3 the native USB port means no external USB-TTL adapter and console +
debug over one cable. The classic ESP32 has no USB peripheral, so the shell goes
out the TX/RX pins through the board's bridge chip.

> **Portability:** ESP-IDF abstracts the drivers, so application code is shared.
> The few genuine target divergences to keep in mind: don't pin tasks to core 1
> (the C3 is single-core); deep-sleep wake config differs (Xtensa `ext0/ext1`
> vs. RISC-V GPIO wake — relevant to TX power mgmt, DE-06); and pin numbers stay
> in Kconfig since the usable GPIO maps differ.

Commands so far (`help` lists them):

| Command | Purpose |
|---|---|
| `help` | List commands. |
| `id` | Chip unique ID (base MAC), model/revision, IDF version. |
| `light [on\|off\|toggle]` | Drive / read the stand-in brake-light GPIO (no arg = show state). |

## Build

Requires [ESP-IDF](https://docs.espressif.com/projects/esp-idf/en/stable/esp32c3/get-started/)
(v5.3+). With the IDF environment sourced:

```bash
cd brake_light/software
idf.py set-target esp32      # or esp32c3 (re-run set-target to switch)
idf.py menuconfig            # optional: set the stand-in light GPIO for your board
idf.py build
idf.py flash monitor         # on attached hardware (Ctrl-] to exit the monitor)
```

`idf.py monitor` attaches to whichever console the target selected; type `help`
at the `chmbl>` prompt. The stand-in light pin defaults to the onboard LED of
each target's reference board (**GPIO2** on the classic ESP32-DevKitC, **GPIO8**
on the ESP32-C3-DevKitM/C). Change it under *Brake_light configuration →
Stand-in brake-light GPIO number*, or override `CONFIG_CHMBL_LIGHT_GPIO`.

## CI

[`.github/workflows/firmware-build.yml`](../../.github/workflows/firmware-build.yml)
builds this project with the real ESP-IDF toolchain (`espressif/esp-idf-ci-action`,
target `esp32c3`) on every push/PR that touches the firmware, confirming it compiles.

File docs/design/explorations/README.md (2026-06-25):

# Design explorations (future-state)

Parking lot for **future-state** design directions that we want on record but are
**not** part of the committed [build order](../README.md#3-design-elements-build-order).
Unlike a [design element](../README.md) (`de-*.md`) — a self-contained slice we build
and prove now — an *exploration* is a sketch of a direction we may take later. It does
**not** get an FFL-traced isolation test or a slot in the status table until it's
promoted to a real design element.

Use these to capture rationale, trade-offs, and open questions while they're fresh, so
the eventual element doesn't start from a blank page.

| Exploration | Area | Status |
|---|---|---|
| [Magnetic mounting](mounting-magnetic.md) | brake_light enclosure / mount | 💭 exploring |

Legend: 💭 exploring · ⏳ ready to promote to a `de-*` element.

> These are **ideas under consideration**, not commitments. The current baseline
> mount in [`hardware.md`](../../hardware.md) and the hard safety rules in
> [`safety-regulatory.md`](../../safety-regulatory.md) still govern anything we
> actually build until an exploration is promoted.

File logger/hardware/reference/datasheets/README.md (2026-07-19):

# Data logger PCB datasheets

The PDF files in this directory are intentionally ignored by Git. Download the
English-language datasheets from the manufacturer links below when needed.

| Designator | Manufacturer | Part number / document | Manufacturer source |
| --- | --- | --- | --- |
| D1 | Nexperia | PTVS3V3D1BALYL | [Datasheet (PDF)](https://assets.nexperia.com/documents/data-sheet/PTVS3V3D1BAL.pdf) |
| D2 | Nexperia | PTVS3V3D1BALYL | [Datasheet (PDF)](https://assets.nexperia.com/documents/data-sheet/PTVS3V3D1BAL.pdf) |
| D3 | Littelfuse | SM24CANB-02HTG | [Datasheet (PDF)](https://www.littelfuse.com/assetdocs/littelfuse-tvs-diode-array-sm24canb-datasheet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) |
| D4 | SMC | 20CJQ060 | [Datasheet (PDF)](https://www.smc-diodes.com/propdf/20CJQ060%20N0672%20REV.A.pdf) |
| D5 | Lite-On | LTST-C190KGKT (green LED) | [Datasheet (PDF)](https://optoelectronics.liteon.com/upload/download/DS22-2000-074/LTST-C190KGKT.PDF) |
| D6 | Lite-On | LTST-C190KRKT (red LED) | [Datasheet (PDF)](https://optoelectronics.liteon.com/upload/download/DS-22-99-0151/LTST-C190KRKT.PDF) |
| J2 | G-Switch | GT-USB-7010ASV | Manufacturer-hosted document was not publicly available; [authorized distributor listing](https://jlcpcb.com/partdetail/gswitch-GT_USB7010ASV/C2988369) |
| J3 | JST | S5B-PH-SM4-TB(LF)(SN) | [PH connector datasheet (PDF)](https://www.jst-mfg.com/product/pdf/eng/ePH.pdf) |
| J4 | JST | S4B-PH-SM4-TB(LF)(SN) | [PH connector datasheet (PDF)](https://www.jst-mfg.com/product/pdf/eng/ePH.pdf) |
| J5 | Molex | 104031-0811 | [Product specification (PDF)](https://www.molex.com/content/dam/molex/molex-dot-com/products/automated/en-us/productspecificationpdf/104/104031/PS-104031-001-001.pdf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) |
| L1 | Murata | LQH5BPN2R2NT0L | [Manufacturer product page](https://www.murata.com/en-us/products/productdetail?partno=LQH5BPN2R2NT0L) |
| Q1 | onsemi | 2N7002K | [Datasheet (PDF)](https://www.onsemi.com/pdf/datasheet/2n7002k-d.pdf) |
| U1 | Espressif | ESP32-S3-WROOM-1-N8 module | [Module datasheet (PDF)](https://www.espressif.com/sites/default/files/documentation/esp32-s3-wroom-1_wroom-1u_datasheet_en.pdf) |
| U1 | Espressif | ESP32-S3 chip | [Chip datasheet (PDF)](https://www.espressif.com/sites/default/files/documentation/esp32-s3_datasheet_en.pdf) |
| U1 | Espressif | ESP32-S3 technical reference manual | [TRM (PDF)](https://documentation.espressif.com/esp32-s3_technical_reference_manual_en.pdf) |
| U2 | Texas Instruments | TCAN330 | [Datasheet (PDF)](https://www.ti.com/lit/ds/symlink/tcan330.pdf) |
| U3 | STMicroelectronics | USBLC6-2P6 | [Datasheet (PDF)](https://www.st.com/resource/en/datasheet/usblc6-2.pdf) |
| U4 | Texas Instruments | TPS62162DSGR | [Datasheet (PDF)](https://www.ti.com/lit/ds/symlink/tps62162.pdf) |
| SW1, SW2 | Mitsumi | R-668003 tactile switch | [Authorized distributor product and datasheet](https://www.digikey.com/en/products/detail/mitsumi/R-668003/11591279) |

Resistors and capacitors are deliberately omitted. SW1 and SW2 are intentionally
DNI on prototype builds: their 1210 pads reserve a recovery option if a board
cannot be programmed through the ESP32-S3 USB serial port.

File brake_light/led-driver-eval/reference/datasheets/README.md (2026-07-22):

# LED driver eval board datasheets

The PDF files in this directory are intentionally ignored by Git. Download the
English-language datasheets from the manufacturer links below when needed.

| Designator | Manufacturer | Part number / document | Manufacturer source |
| --- | --- | --- | --- |
| C2 | Taiyo Yuden | LMK107B7105KA-T (1µF, 0603) | [Datasheet (PDF), via LCSC](https://www.lcsc.com/product-detail/multilayer-ceramic-capacitors-mlcc-smd-smt_taiyo-yuden-lmk107b7105ka-t_C92806.html) |
| C4 | YAGEO | CC0603KRX7R9BB224 (0.22µF, 0603) | [Datasheet (PDF), via LCSC](https://www.lcsc.com/product-detail/Multilayer-Ceramic-Capacitors-MLCC-SMD-SMT_YAGEO_C107083.html) |
| L1 | Sunlord | SWPA5020S220MT (22µH, 1.1A) | [SWPA series datasheet (PDF)](https://www.sunlordinc.com/uploads/files/20221122/SWPA%20series%20of%20SMD%20Power%20Inductor.pdf) |
| R4 | YAGEO | PE1206FRF470R56L (560 mΩ, 1%, current-sense) | [Datasheet (PDF), via LCSC](https://www.lcsc.com/product-detail/C5844413.html) |
| U3 | Diodes Incorporated | AP3019AKTR | [Datasheet (PDF)](https://www.diodes.com/assets/Datasheets/AP3019A.pdf) |

`U3` and its surrounding components (`C2`, `C4`, `L1`, `R4`) implement the AP3019A
buck-boost LED driver reference design — see [`led_drv_eval.kicad_prl.kicad_sch`](../../led_drv_eval.kicad_prl.kicad_sch).

`TP1`–`TP6` (test points) are intentionally DNI and omitted here — they're bare
probe pads, not sourced parts.

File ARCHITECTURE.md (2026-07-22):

# Open-CHMBL — System Architecture

**Open-sourCe Helmet-Mounted Brake Light** for motorcyclists.

A battery-powered LED bar worn on the rider's back — magnetically clamped to a
**jacket or backpack** between the shoulder blades — lights up when the motorcycle
is braking. Brake state is derived from the bike's **CAN bus** (via the diagnostic
port) and sent wirelessly to the rider-side unit over **ESP-NOW**.

> The name is aspirational: helmet fitment is deferred for the first build (shell
> curvature + helmet certification make it a harder problem). The rider-side
> hardware currently targets the **fabric attachment** case only — see
> [`docs/hardware.md §2`](docs/hardware.md#2-brake_light-rider-side).

> ⚠️ **Read [`docs/safety-regulatory.md`](docs/safety-regulatory.md) first.**
> This is an **auxiliary** light. It does not replace the motorcycle's own legally
> required brake light, and helmet-mounted lighting is restricted or prohibited in
> some jurisdictions. Treat this project as track/off-road/educational until you
> have confirmed legality for your use.

---

## 1. Why this approach

Two existing patent families constrain the obvious designs:

- **Tapping the brake-light wires** directly (galvanic/optoisolated tap on the
  bike's stop-lamp circuit).
- **Inertial detection** — using an accelerometer/gyro on the helmet or light to
  infer deceleration.

Open-CHMBL deliberately avoids both. Instead it reads vehicle data from the **CAN bus
exposed on the modern Euro 5 diagnostic port** — a data-only, read-only interface that
does not modify any bike wiring.

On the reference bike (Triumph Speed 400) the **brake-switch state is not published on
the CAN bus** — repeated captures found no brake bit. The signals that *are* present and
displayed on the instrument cluster — **wheel speed** and **gear/neutral** — plus the
confirmed **throttle** and **clutch** signals are enough to do something a stop-lamp tap
cannot: infer braking from **deceleration of the bike's own wheel-speed signal**, and
distinguish steady cruise, accelerating away, and a hold at a standstill.

Crucially, the deceleration estimate is derived from **CAN wheel-speed data, not an
on-board accelerometer/gyro**, so it stays clear of the inertial-detection patent family
above. See [§4](#4-braking-state-machine) for the resulting state machine.

---

## 2. System overview

```
        MOTORCYCLE                              RIDER (jacket / pack)
 ┌──────────────────────────┐              ┌───────────────────────────┐
 │  6-pin diagnostic port    │              │  RX unit                  │
 │     │ CAN-H / CAN-L        │              │  ┌─────────────────────┐  │
 │     ▼                      │   ESP-NOW    │  │ ESP32-C3            │  │
 │  ┌───────────────────┐     │  (2.4 GHz,   │  │  • RX callback      │  │
 │  │ TX unit            │    ))) encrypted, │  │  • state interpret  │  │
 │  │  • CAN transceiver │     │   pre-paired)│  │  • LED pattern eng. │  │
 │  │  • ESP32-S3 (TWAI  │ ─ ─ ─ ─ ─ ─ ─ ─►  │  │  • ambient dimming  │  │
 │  │    listen-only)    │     │              │  │  • battery monitor  │  │
 │  │  • bike-profile    │     │              │  └─────────┬───────────┘  │
 │  │    decoder         │     │              │            ▼              │
 │  │  • state machine   │     │              │     ~8″ red LED bar       │
 │  │  • ESP-NOW TX       │     │              │     + LED driver         │
 │  └───────────────────┘     │              │     1S 18650 + USB-C      │
 │  Powered from bike (12 V)   │              │  Magnetic to fabric       │
 └──────────────────────────┘              └───────────────────────────┘
```

Two independent units:

| Unit | Lives on | Power | Job |
|---|---|---|-----|
| **`transmitter/`** (bike-side, "TX") | Plugs into the diagnostic port | Bike 12 V (switched) | Sniff CAN, decode brake/RPM/throttle/clutch, run the braking state machine, broadcast state over ESP-NOW |
| **`brake_light/`** (rider-side, "RX") | Magnetically clamped to the jacket / backpack (helmet fitment deferred) | On-board 1S 18650 Li-ion, USB-C charge | Receive state, drive the ~8″ LED bar with the right pattern/brightness, manage battery & link health |

> Throughout these docs "TX" = the `transmitter` unit and "RX" = the `brake_light` unit.

> TX runs an **ESP32-S3** (not the C3 shown for RX above) — the TX hardware plan
> reuses the [`logger/`](logger) PCB, which needed the S3's SDMMC peripheral for its
> microSD slot. RX has no SD card and stays on the ESP32-C3. See
> [`docs/hardware.md §1`](docs/hardware.md#1-transmitter-bike-side).

The TX does all interpretation. The RX is intentionally "dumb": it renders whatever
discrete state the TX tells it to, plus a couple of local concerns (brightness vs.
ambient light, battery, link-loss fault). Keeping the logic on one side makes the
protocol small and the failure modes easy to reason about.

---

## 3. Reference-bike-first strategy

Wheel speed, throttle, RPM, clutch and gear are **not** reliably available as standard
OBD-II PIDs on motorcycles (and **brake-switch state may not be on the bus at all** — on
the reference bike it isn't). The signals that exist live in manufacturer-specific CAN
frames whose IDs and bit layouts must be reverse-engineered per model. Trying to be
universal on day one is the fastest way to ship nothing.

So: **pick one reference motorcycle, reverse-engineer it fully, prove the whole
chain, then generalize.** The decoder is written against a small per-bike "profile"
(CAN ID + bit offsets + scaling) so adding a second bike later is a data change, not
a rewrite — but we only fill in one profile now.

**The reference bike is the Triumph Speed 400.** Its sibling **Scrambler 400 X**
shares the same TR-series 398 cc single powertrain/ECU, so one profile is expected to
cover both. The **Street Triple 765** is a stretch target — a different platform
(triple, separate ECU = its own profile) but the same red 6-pin diagnostic connector,
so the TX hardware carries over. Both expose CAN-H/CAN-L (plus a K-line) on a red
6-pin OBD2 port under the seat. See
[`docs/can-profiles.md`](docs/can-profiles.md) for the sniffing methodology, the
profile data structure, and **[`docs/can-profiles.md#5-reference-target--triumph-speed-400-tr-series-platform`](docs/can-profiles.md#5-reference-target--triumph-speed-400-tr-series-platform)**
for the connector details and decode table.

> ⚠️ The single biggest unknown for these bikes is whether the diagnostic port
> exposes **free-running broadcast** CAN (which our listen-only sniffer can read) or
> only **request/response** diagnostic data. Resolving that is the first job in
> Phase 2 — see the CAN doc.

---

## 4. Braking state machine

Because the reference bus has **no brake-switch bit**, the TX infers the light from
**wheel-speed-derived acceleration**, qualified by clutch and gear/neutral context.
Brightness and pattern for each state are decided on the RX.

**Inputs (from CAN):**
- `wheel_speed` — cluster wheel/road speed; the primary input (converted to MPH).
- `clutch_pulled` — clutch lever switch (confirmed present on the reference bus).
- `gear` / `neutral` — gear position / neutral indicator (shown on the cluster).
- `throttle_pct`, `rpm` — confirmed present; retained for diagnostics/telemetry, not
  required by the state machine.

**Derived:** `accel` — the slope of a smoothed `wheel_speed`, in MPH/s (− = decel). This
is the core trigger.

**Output states** (the light is effectively binary on/off; two on-states exist because
their *off* conditions differ):

| State | Condition (sketch) | Meaning | Render |
|---|---|---|---|
| `OFF` | Accelerating, steady cruise, or armed-but-idle | Not braking | Light off (or dim running light) |
| `BRAKING` | Deceleration exceeds a threshold while moving | Bike is slowing | **Bright, solid red** |
| `STOPPED` | At/near a standstill (held on) | Bike has stopped | **Bright, solid red** |

`BRAKING` and `STOPPED` are both sent to the helmet as `BRAKE` (light on). The protocol
keeps a `DECEL` value **reserved** for a possible future soft-cue tier.

Design rationale:

- **Deceleration is the signal.** With no stop-lamp flag, "the bike is slowing harder
  than `DECEL_ON_MPHPS`" is the braking trigger. It comes from the bike's CAN
  wheel-speed (not an IMU), keeping clear of the inertial-detection patent.
- **Two thresholds, with hysteresis.** A larger deceleration turns the light *on*; a
  positive acceleration (above a minimum speed) or a sustained steady speed turns it
  *off*. Different on/off conditions prevent chatter around any single threshold.
- **Stop handling.** Coasting below `STOP_SPEED_MPH` turns the light on (or keeps it on)
  and *holds* it through a standstill — a stopped bike should read as braking to
  following traffic. It releases when the bike pulls away, when the **clutch is released
  in gear** (launching — this is where the gear/neutral signal earns its keep, since a
  neutral stop must *not* be read as a launch), or after a long-stop timeout.
- **Anti-strobe.** A global minimum-dwell floor gates all transitions so the light can't
  strobe. Flashing brake lights are illegal in many places anyway — see safety doc.

Full transition table, thresholds, and timing live in
[`docs/firmware.md#braking-state-machine`](docs/firmware.md#braking-state-machine); the
rationale and the SMC model are in
[`docs/design/de-09-brake-decel-logic.md`](docs/design/de-09-brake-decel-logic.md).

---

## 5. Wireless link (ESP-NOW)

- **Pre-paired, encrypted, connectionless.** TX and RX exchange MACs once during a
  pairing ritual, then store each other as encrypted ESP-NOW peers (PMK/LMK). No
  Wi-Fi AP, no pairing on the road.
- **Heartbeat model.** The TX transmits state at a fixed rate (target **20–50 Hz**)
  whether or not state changed. The RX treats *absence* of packets as a fault.
- **Link-loss failsafe.** If the RX hasn't heard a valid packet within a timeout
  (target **≤ 300 ms**), it enters a **distinct "link-lost" indication** — a steady
  running light plus a slow fault blink. It must **not** assume "no packet = not
  braking" (silently going dark) and must **not** latch a stale `BRAKE` on forever.
- **End-to-end latency budget:** brake event → LED ≤ **100 ms** (CAN read + state
  machine + ESP-NOW hop + LED update). ESP-NOW itself is single-digit ms.
- **Message integrity:** sequence number for replay/staleness detection; ESP-NOW's
  built-in encryption + a small app-level check.

Message formats, pairing procedure, sequence/failsafe details:
[`docs/protocol.md`](docs/protocol.md).

---

## 6. Critical safety constraints (summary)

These are hard requirements, expanded in [`docs/safety-regulatory.md`](docs/safety-regulatory.md):

1. **CAN is listen-only.** The ESP32 TWAI controller runs in **listen-only / silent
   mode** — it never ACKs and never transmits on the bike bus. We must not risk
   disturbing the motorcycle's own ECUs.
2. **Auxiliary, not a replacement.** Open-CHMBL never substitutes for the bike's
   factory brake light.
3. **Mount safety.** Baseline fabric mount uses **magnets that peel off** under
   shear — the magnetic interface *is* the frangible/breakaway release, satisfying
   the safety doc's snag-and-crash requirements without a separate breakaway pin.
   Keep mass low. The **helmet variant** (deferred) inherits the same hard rule:
   non-penetrating only, never drill the shell.
4. **No false braking, no strobing.** Failsafes bias toward an honest, non-alarming
   state. Flashing patterns are disabled by default for legal reasons.
5. **Parasitic draw.** The TX must sleep / cut load when the bike is off so it can't
   flatten the motorcycle battery.

---

## 7. Repository layout (planned)

Documentation now; code later. Anticipated structure:

```
open-chmbl/
├── ARCHITECTURE.md            ← this file (index + overview)
├── README.md
├── docs/
│   ├── feature-functions.md   ← per-device capability decomposition (FFL IDs)
│   ├── cli.md                 ← developer CLI to fake/view I/O (isolation testing)
│   ├── hardware.md            ← BOM, power, connectors, enclosures
│   ├── firmware.md            ← tasks, state machine, config, build
│   ├── protocol.md            ← ESP-NOW message + pairing + failsafe
│   ├── can-profiles.md        ← CAN sniffing method + per-bike profile format
│   ├── safety-regulatory.md   ← legal, functional safety, helmet safety
│   ├── roadmap.md             ← phased plan, milestones, open questions
│   └── design/                ← per-element design docs (build one at a time)
│       ├── README.md          ← process, template, design-element build order
│       └── de-*.md            ← ESP-NOW, auto-brightness, link-loss, CAN, BRAKE/DECEL
├── transmitter/               ← bike-side unit
│   ├── hardware/              ← schematics, BOM, connector, enclosure
│   └── software/              ← ESP32 firmware (TWAI listen-only + ESP-NOW TX)
└── brake_light/               ← rider-side unit (fabric mount this rev)
    ├── hardware/              ← LED bar, LiPo+charge, mount, enclosure
    └── software/              ← ESP32 firmware (ESP-NOW RX + LED engine)
```

Each unit and each `hardware/`/`software/` subdirectory has its own README. The
shared protocol/profile/state definitions are referenced from both `software/`
directories — see [`docs/roadmap.md`](docs/roadmap.md) for whether they become a
real shared library or duplicated headers.

---

## 8. How we build it

We don't use shall-statement requirements. Instead:
**[feature-function lists](docs/feature-functions.md) → [design elements](docs/design/README.md)
→ isolated implementation → integration.** Each design element is built and proven on
its own, with its inputs **faked** and outputs **viewed** through the per-device
[developer CLI](docs/cli.md). The element build order lives in
[`docs/design/README.md`](docs/design/README.md).

## 9. Where to go next

- The capabilities, per device: [`docs/feature-functions.md`](docs/feature-functions.md)
- The build process & element order: [`docs/design/README.md`](docs/design/README.md)
- The developer CLI (fake/view I/O): [`docs/cli.md`](docs/cli.md)
- Understand the parts and power: [`docs/hardware.md`](docs/hardware.md)
- Understand the code structure & state machine: [`docs/firmware.md`](docs/firmware.md)
- Understand the radio link: [`docs/protocol.md`](docs/protocol.md)
- Reverse-engineer the reference bike: [`docs/can-profiles.md`](docs/can-profiles.md)
- **Before building anything physical:** [`docs/safety-regulatory.md`](docs/safety-regulatory.md)
- The plan and what's undecided: [`docs/roadmap.md`](docs/roadmap.md)

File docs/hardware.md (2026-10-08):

# Hardware

Two boards: the **transmitter** (bike-side) and the **brake_light** (rider-side —
fabric-mounted, this rev). Everything here is a first-pass sketch to size the design
— not a finalized BOM.

---

## 1. Transmitter (bike-side)

Lives at the diagnostic port. Powered from the bike. Read-only on CAN.

**Hardware plan: reuse the [`logger/`](../logger) PCB.** The logger's board
(ESP32-S3-WROOM-1 + onboard CAN transceiver + protected 12 V/USB-C power, see
[`logger/hardware/README.md`](../logger/hardware/README.md)) was designed to double
as the transmitter with its microSD slot (J5) and button/LED breakout (J4) left
unpopulated — the transmitter needs neither. This supersedes the earlier
ESP32-C3 + SN65HVD230 sketch below the block diagram; the C3 remains the MCU for
`brake_light/` (§2), which has no SD card and so doesn't need the S3's SDMMC
peripheral.

> ⚠️ The logger board has an open strapping-pin issue (a pull-up on the ESP32-S3's
> `GPIO45` VDD_SPI boot strap) — see
> [`logger/hardware/README.md §5`](../logger/hardware/README.md#5-known-issue--gpio45s-pin-conflicts-with-a-boot-strap)
> before building a transmitter board off this design.

### Block diagram

```
 J3 (bike)                     USB-C (J2)
 12 V ──▶┌───────────┐  +5VD  VBUS──▶┌──────────────┐
 GND ───▶│ Schottky   │──────────────▶│  TPS62172     │──▶ 3V3 rail
         │ reverse-pol│                │  (buck)       │       │
 CAN-H ─▶│ + TVS      │                └──────────────┘       │
 CAN-L ─▶└───────────┘                                          │
                                                                  ▼
                              CAN transceiver ──────────▶ ESP32-S3 TWAI
                              (TCAN330, 3.3 V,             (listen-only)
                               silent-mode pin)                  │
                                                                  └─▶ ESP-NOW (2.4 GHz)
```

### Parts (as reused from the logger board)

| Function | Part | Notes |
|---|---|---|
| MCU + radio | **ESP32-S3-WROOM-1-N4** | 4 MB flash, no PSRAM — build for 4 MB or the app boot-loops (see [`logger/hardware/BRINGUP.md §3`](../logger/hardware/BRINGUP.md)). Has built-in **TWAI** (CAN 2.0) controller; only a transceiver is needed. Chosen over the C3 on the logger board for its SDMMC peripheral — not needed here, but the transmitter reuses that same board. |
| CAN transceiver | **TCAN330** (3.3 V) | 3.3 V logic, silent-mode pin wired to a GPIO for a hardware-level listen-only default (see the GPIO45 caveat above). |
| Power regulation | **TPS62172** buck, 12 V→3.3 V (via a diode-ORed +5VD rail shared with USB-C) | Not automotive-load-dump-rated in this rev — a Schottky diode handles reverse-polarity, not a FET. Revisit for full-time bike use; fine for bench/prototype. |
| Input protection | Schottky diode (reverse-pol.) + dual TVS on CAN-H/CAN-L | See [`logger/hardware/README.md §2`](../logger/hardware/README.md#2-power). |
| Ignition sense | Tap switched-12 V or detect bus activity | Not yet on the logger board — needed for TX-specific sleep behavior (DE-06); would be a board delta from the shared logger design. |
| Connector | JST-PH 5-pin (J3): CAN-L, CAN-H, +12 V, GND, spare | Board-side connector. Bike-specific diagnostic plug (Euro 5 6-pin is common) still needs its own adapter/harness — **verify pinout per bike**, pin assignment is not universal. |
| Enclosure | Potted/sealed, **IP65+** | Engine bay vibration + weather + heat. Not designed yet. |

### Power & parasitic draw

- The diagnostic port may provide **constant** or **switched** 12 V depending on the
  bike. If constant, the TX **must** sleep (deep sleep, transceiver disabled) when it
  sees no CAN activity, and ideally cut the buck's load, so it cannot drain the
  motorcycle battery while parked. Target parked draw: **< 1 mA**.
- Wake on CAN bus activity (transceiver wake / RXD edge) or on ignition sense.

---

## 2. Brake_light (rider-side)

Self-contained, battery powered, charges over USB-C. This is the part the rider
sees and touches, so usability (charging, on/off, brightness) matters.

**Form factor** (this rev): a **thin, short (vertical, viewed from the rear), wide
~8″ LED bar** that clamps magnetically to the outside of a **jacket or backpack**,
between the shoulder blades — a thin steel strip or washers inside the garment /
pack completes the mount. Helmet fitment and cross-form interchangeability are
**deferred** so shell curvature and helmet-certification questions don't gate the
first build. See the [garment / backpack mount exploration](design/explorations/mounting-magnetic.md#exploration-a--garment--backpack-shoulder-mount).

### Block diagram

```
 USB-C ──▶ Charge IC ──▶ 1S 18650 ──▶ Load-share ──▶ Boost/LDO ──▶ 3V3 ──▶ ESP32-C3
 (5 V)    (MCP73871,     (protected     path                       │       (bare
          chip-down)      cell)                                    │        WROOM-02
                                                                    │        module)
 Ambient-light sensor ─────────────────────────────────────────▶ │
 Fuel-gauge / ADC ─────────────────────────────────────────────▶ │
                                                                    ├─▶ LED driver ──▶ ~8″ red LED bar
                                                                    │   (LM3410 boost CC,
                                                                    │    chip-down)
                                                                    ├─▶ Mode/pair button
                                                                    └─▶ Status WS2812
                                                                        (2020/Mini,
                                                                         chip-down,
                                                                         separate from bar)
```

Everything except the ESP32-C3 module itself is **chip-down** on the brake_light PCB
— the earlier "grab a dev board with the charger already on it" path (removed §2.1
survey) is dropped in favor of an integrated design that fits the thin/wide form
factor.

### Parts (sketch)

| Function | Candidate part | Notes |
|---|---|---|
| MCU + radio | **ESP32-C3-WROOM-02** (bare module) | Same C3 family as before; module rather than dev-board so we can lay the PCB flat and thin. Placed as-is, no dev-board freebies. |
| Battery | **1S 18650 Li-ion, protected cell**, ~3000 mAh typical | Cylindrical Li-ion chosen over pouch/LiPo because pouch cells need compression the thin enclosure can't provide. Protected cell means the load-share IC does **not** need to double as cell protection. **18 mm diameter sets the enclosure-thickness floor.** |
| Cell attach | **Undecided — open question** | Three viable options: **Keystone 1043** (low-profile top-mount holder — user-swappable, adds ~1–2 mm over cell diameter), **Keystone 54** (end clips only — thinnest; cell sits on the PCB but enclosure has to open for swap), or **cell with a factory JST-PH pigtail** (no board footprint; swap requires re-plugging inside the sealed enclosure). Decide during enclosure design; all three preserve the same charger / load-share design. |
| Charge IC | **MCP73871** (chip-down) | Does **load sharing** so the light runs while charging from USB-C. Directly-placed part, not a module. |
| USB-C | USB-C receptacle w/ CC resistors + ESD protection | 5 V sink only. |
| LED array | **Discrete 620–630 nm red** (mid-power 2835/3030, ~8–12 emitters) laid out linearly along the **~8″ bar** in series string(s) + **boost constant-current driver** | Emitter/flux **down-selected** in [`led-brightness-benchmark.md`](led-brightness-benchmark.md) (~50–80 cd daylight, ~60–100 lm installed red); series-string + boost **topology** in [`de-04`](design/de-04-led-render.md). Series count per string capped by the driver's V<sub>out</sub> ceiling (≤ ~8 mid-power reds ≈ 18 V for LM3410's 24 V); split into parallel strings beyond that. Addressable RGB is too dim per-pixel for the bar → status indicator only. |
| LED driver IC | **TI LM3410(X)** boost CC (chip-down) | 2.7–5.5 V in (uses the full 1S Li-ion discharge, 3.0–4.2 V), 2.8 A / **24 V** integrated switch, PWM + analog dim, OVP/thermal; ~$1.5, LCSC. 24 V ceiling caps a single string at ~8 mid-power reds — tall single strings (10–12) or higher V<sub>out</sub> want the upgrade parts: ADI **LT3922‑1** (synchronous 34 V, spread-spectrum, AEC‑Q100) or LCSC-native **DIO5661** (37 V). **MAX16833 rejected** (5 V Vin-min — can't run on 1S). [`de-04 §3.3`](design/de-04-led-render.md). |
| Brightness control | PWM dimming (driver DIM pin) + analog current trim + **ambient light sensor** | Night brightness must not blind following drivers; day brightness must be visible in sun. Auto-dim is a real safety feature, not a nicety. Day/night intensity endpoints (~50–80 cd → ~5–15 cd) set in [`led-brightness-benchmark.md §4`](led-brightness-benchmark.md#4-design-target-for-the-helmet-bar). Keep dimming PWM > flicker fusion — distinct from the illegal *flashing*. |
| Battery monitor | Fuel gauge IC or ADC divider | Low-battery warning pattern + cutoff. |
| User I/O | One button | Power, pairing, brightness cycle. |
| Status indicator | **Discrete WS2812B** (`WS2812B-2020` or `WS2812B-Mini`), chip-down, **separate from the main bar** | Chip-down since we're on a bare module now (no free onboard RGB). Discrete status/fault by **color + blink code** (pairing, link, charge, fault) — legible even when the bar is off. See [`de-10`](design/de-10-status-indicator.md). |
| Mount (baseline) | **Magnetic to jacket / backpack fabric** — magnets in the light assembly, thin steel strip / washers inside the garment or pack | The magnetic interface is its own **shear / peel release**, satisfying the safety doc's breakaway requirement without a separate frangible pin. Sizing/pole geometry TBD. **No helmet target this rev**; helmet fitment stays in the [magnetic mount exploration](design/explorations/mounting-magnetic.md). |
| Enclosure | **IP65+**, thin (governed by the 18650), short vertically, ~8″ wide | Low profile matters for on-body wear comfort and for staying below the rider's line of sight to the mirrors. |

### Runtime budgeting (worked example)

LED current dominates. Rough sizing with a typical protected 18650 (~3000 mAh
usable capacity, take ~85 % to end-of-life):

```
Avg LED draw (mixed off/decel/brake, auto-dimmed)  ≈  120 mA
ESP32-C3 (RX mostly, modem on)                     ≈   30 mA
                                                   ----------
System average                                     ≈  150 mA

3000 mAh × ~0.85 usable / 150 mA                   ≈  17 h
```

That comfortably covers multi-day riding between charges (versus ~8.5 h with the
earlier 1500 mAh LiPo). Brake events are brief and bright; the *average* is what
sets runtime, so auto-dimming and an `OFF`/dim-running idle state matter a lot.
The extra headroom lets us hold the LED currents at the daylight-visibility target
without shrinking the runtime story.

### 2.1 Parts direction: bare module + chip-down

**Decision:** the brake_light uses a **bare `ESP32-C3-WROOM-02` module** and places
the charger, DC-DC, LED driver, status WS2812, and USB-C front-end **chip-down** on
the brake_light PCB. The earlier dev-board-with-freebies survey (LOLIN C3 Pico,
FireBeetle 2, XIAO C3, Olimex Lipo, etc.) is superseded and removed.

Why the pivot:

- **Form factor.** The rider-side unit is now a **thin, wide (~8″), short-in-vertical
  LED bar** that clamps magnetically to a jacket or backpack. That geometry wants a
  flat, custom-shaped PCB with the LED bar and 18650 laid out on it — a piggybacked
  dev board (with its own USB connector, headers, and vertical parts) doesn't fit.
- **Chip-down parts are already in the family.** The load-share charger
  (`MCP73871`), boost CC driver (`LM3410`), 3V3 buck, and WS2812B-2020 are all
  LCSC-stocked and small enough to place in the bar's own outline. Skipping the
  dev-board wrapper saves height and mm of board.
- **Status indicator is no longer "free."** The de-10 status LED becomes a
  **discrete WS2812B (2020 / Mini)** chip-down part — cheap, one GPIO, positioned
  wherever the enclosure can actually show it (dev-board WS2812s were often buried).
  DE-10 already flagged this trade — see its open items.

The bare-module + chip-down BOM is fully LCSC-sourceable (`ESP32-C3-WROOM-02`,
`MCP73871`, `LM3410`, `WS2812B-2020` / `-Mini`), which is the same "clean supply
chain" argument the earlier survey landed on for a bare module anyway.

---

## 3. Open hardware questions

- Exact diagnostic connector + pinout for the **reference bike** (see
  [`can-profiles.md`](can-profiles.md)).
- ~~LED bar: addressable vs. discrete high-power red~~ — **resolved**: **discrete
  620–630 nm red mid-power array (~8–12 emitters) on a boost constant-current driver**,
  sized to a car-CHMSL intensity band (~50–80 cd daylight) in
  [`led-brightness-benchmark.md`](led-brightness-benchmark.md), with the series/boost
  topology + driver (**TI LM3410**) selected in [`de-04`](design/de-04-led-render.md).
  Addressable RGB is too weak per-pixel for the bar and stays the status indicator only.
  Remaining sub-question: final emitter part/bin, optic/diffuser, and exact emitter count
  (which also sets series-vs-parallel string layout against the driver's V<sub>out</sub>).
- ~~ESP32-C3 module choice~~ — **resolved**: bare `ESP32-C3-WROOM-02` + chip-down
  charger / DC-DC / LED driver / status WS2812 (§2.1). The integrated-module survey
  is no longer relevant to this form factor.
- **18650 cell attachment**: pick between **Keystone 1043** (low-profile top-mount
  holder), **Keystone 54** (end clips only — thinnest), or a **cell with a JST-PH
  pigtail** (no board footprint). All three preserve the same charger / load-share
  design; the decision belongs with the enclosure pass because it drives the
  serviceability story (open-the-case-to-swap vs. slide-in). Assume a protected cell
  regardless.
- **Mount direction (fabric case):** magnet size / pole geometry / retention force
  vs. clean-release for the jacket/backpack magnetic mount — see the
  [garment / backpack exploration](design/explorations/mounting-magnetic.md#exploration-a--garment--backpack-shoulder-mount).
  Helmet fitment is deferred (own exploration B in that doc).
- Whether to add a small inertial sensor purely as a *cross-check / tamper or
  fallen-helmet detector* (NOT for brake detection — that's the patented approach we
  avoid). Deferred.

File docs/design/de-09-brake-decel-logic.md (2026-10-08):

# DE-09 — Braking state machine

**Status:** 🟢 implemented · **Device(s):** transmitter · **Depends on:** DE-00, DE-08

The braking state machine: fuse the decoded CAN signals into a `BRAKE` / `OFF` light
decision. The reference bike (Triumph Speed 400) **does not publish a brake-switch bit
on its CAN bus**, so braking is **inferred from wheel-speed-derived acceleration**,
qualified by clutch and gear/neutral context. Designed as a **pure function** so it can
be developed and unit-tested entirely from faked signals — no CAN, no radio. See
[`firmware.md §braking-state-machine`](../firmware.md#braking-state-machine).

The state machine lives in `transmitter/software/main/brake_fsm.c` as a plain,
dependency-free C function, ticked at 50 Hz by `brake_ctl.c`. This document is the
rationale; `brake_fsm.c` and the reference implementation it is tested against
([§5](#5-firmware-moduletask-decomposition)) are the code.

> **Not SMC.** Earlier drafts specified this machine in an [SMC (State Machine
> Compiler)] `.sm` model compiled by a CMake pre-build step. That was dropped when the
> element was implemented: the calibrated algorithm is three states and one event, and
> an SMC model would have added a **JRE on every build host and in CI** to generate
> ~40 lines of switch. What the tooling was meant to buy — one authoritative definition
> of the transition structure, mechanically checked — is instead bought by
> [`tools/fsm_check.py`](../../tools/fsm_check.py), which asserts the shipping C and the
> reference implementation agree tick for tick over a real ride capture. Revisit if the
> machine grows states (a soft `DECEL` tier would be the trigger).

[SMC (State Machine Compiler)]: https://smc.sourceforge.net/

## 1. Scope & isolation boundary
- **In:** the speed/acceleration derivation (smoothing, MPH/s estimate), the
  `OFF`/`BRAKING`/`STOPPED` transition logic, the steady/stop/anti-strobe timers, the
  clutch-and-gear gating, and the mapping of state → emitted `brake_state_t`.
- **Out (faked at edges):** input signals come from `sig set` (not live CAN — that's
  DE-08); the output is read via `state show` and need not drive a real radio (DE-01).
- **Isolation test:** transmitter board (or host unit test) driving a **synthetic
  speed/clutch/gear profile** and asserting the output state + transition timing.

## 2. FFL traceability
TX-SM-1…6.

## 3. Inputs & derived signals

The machine consumes decoded CAN signals (DE-08) and one **derived** quantity:

| Signal | Source | Use |
|---|---|-----|
| `wheel_speed` → `speed_mph` | CAN (cluster) | Converted to MPH; the primary input. |
| `accel_mphps` | **derived** from `speed_mph` | Signed acceleration (− = decel). The core trigger. |
| `clutch_pulled` | CAN (confirmed present) | Gates the "launching from a stop" exit. |
| `gear` / `neutral` | CAN (cluster) | Distinguishes a parked/neutral stop from a hold-clutch-in-gear stop. |
| `rpm` | CAN | Not required by this FSM; retained for diagnostics/telemetry. |

> **No `brake_switch`.** It is confirmed *absent* from the reference bus, so the FSM
> never sees it. Deceleration is computed from the bike's own CAN **wheel-speed**
> signal, not an on-board accelerometer/gyro — this is what keeps the design clear of
> the inertial-detection patent family (see [ARCHITECTURE §1](../../ARCHITECTURE.md#1-why-this-approach)).

**Acceleration estimate.** `accel_mphps` is *not* a raw sample-to-sample diff — CAN
speed is quantized (~0.039 mph) and noisy, and the whole FSM hinges on a clean
derivative. As implemented in `can_decode.c` (`accel_update`), each wheel-speed frame:

1. goes through a **dt-aware EMA low-pass** with time constant `speed_smooth_ms`
   (80 ms), so quantization steps and single-sample glitches don't become decel spikes;
2. is pushed into a **history ring**, and the slope is taken against the newest sample
   at least `CAN_DECODE_ACCEL_WINDOW_MS` (200 ms) old;
3. has that slope **exponentially smoothed** (`alpha` 0.3) into the reported value.

> **Size the ring against the frame rate.** The reference bus emits `0x102` at ~100 Hz,
> so 200 ms of history is ~20 samples; the ring holds 32. Undersize it and the "newest
> sample ≥ 200 ms old" search never succeeds, so the derived acceleration silently stops
> updating and the light never comes on — the signal stays *valid*, it just stops
> moving. The firmware shipped a 16-deep ring for a while and did exactly this; it is
> the reason `tools/fsm_check.py` exists.

**Signal loss.** `wheel_speed` is the one required input. When it is absent or stale
(`CAN_DECODE_STALE_MS`, 1 s) the machine is forced to `OFF` and rearmed, so a dropout
behaves like a fresh boot. A brake light that latches on because the bus went quiet is
worse than no light at all.

## 4. State machine

**States:** `OFF`, `BRAKING`, `STOPPED`. Both `BRAKING` and `STOPPED` render as
`ST_BRAKE` (light on); `OFF` renders as `ST_OFF`. (`ST_DECEL` is left reserved in the
protocol — see [protocol.md](../protocol.md).)

```
                ┌─────────────────────────────── OFF ───────────────────────────────┐
                │                              (light off)                            │
                │  decel > DECEL_ON                         speed < STOP_SPEED         │
                ▼                                                          ▼
        ┌───────────────┐   speed < STOP_SPEED          ┌───────────────────────────┐
        │   BRAKING      │ ───────────────────────────▶ │          STOPPED           │
        │  (light on)    │                               │        (light on)          │
        └───────┬───────┘                               └─────────────┬──────────────┘
                │  accel > ACCEL_OFF & speed > 5                       │ speed > MOVING_SPEED
                │  OR steady |accel| < band for STEADY_TIMEOUT         │ OR (clutch released in gear & rolling)
                ▼                                                      │ OR stopped > STOP_TIMEOUT
               OFF ◀──────────────────────────────────────────────────┘
```

**Transitions (Poll fired ~50 Hz; first matching guard wins):**

| From | Guard | To | Rule |
|---|---|----|---|
| `OFF` | deceleration > `decel_on_mphps` held for `decel_on_debounce_ms` | `BRAKING` | 1 — turn on when slowing hard |
| `OFF` | `speed_mph` < `stop_speed_mph` | `STOPPED` | 2 — turn on when settling to a stop |
| `BRAKING` | `speed_mph` < `stop_speed_mph` | `STOPPED` | 3 — keep on through the stop |
| `BRAKING` | acceleration > `accel_off_mphps` **and** `speed_mph` > `accel_off_min_speed_mph` | `OFF` | 4 — accelerating away |
| `BRAKING` | \|accel\| < `steady_band_mphps` for `steady_timeout_ms` | `OFF` | 5 — steady cruise after braking |
| `STOPPED` | `speed_mph` > `moving_speed_mph` | `OFF` | 6a — moving away from the stop (hysteresis) |
| `STOPPED` | clutch released **and** in gear (not neutral) **and** `speed_mph` > `stop_speed_mph` | `OFF` | 6b — launching |
| `STOPPED` | stopped for > `stop_timeout_ms` | `OFF` | 6c — parked / long stop |

Notes:
- **Rule 6b uses gear/neutral.** "Clutch released" only means *launching* when the bike
  is in gear (you must hold the clutch in to sit in gear). In **neutral** the guard is
  never true, so a neutral stop holds the light until rule 6a or 6c — exactly the
  parked-at-a-light case.
- **Low-speed hysteresis (rules 6a/6b).** `STOPPED` enters at `speed < stop_speed_mph`
  (1.0) but only exits for motion at `speed > moving_speed_mph` (3.0); the launch guard
  (6b) additionally requires the bike to be **rolling** (`speed > stop_speed_mph`) so it
  cannot ping-pong against the entry rule (rule 2) while sitting still in gear with the
  clutch out. This is what makes creep-in-traffic hold a steady light instead of
  strobing. On the [DE-07 40 mph ride log] the gap cut FSM transitions **162 → 48** and
  sub-0.5 s light blips **65 → 8**. The anti-strobe dwell can't substitute: the guards
  genuinely oscillate across a single threshold, so the fix is hysteresis, not
  rate-limiting.
- **Decel-on debounce (rule 1).** The `OFF → BRAKING` trigger requires
  `decel > decel_on_mphps` to hold **continuously** for `decel_on_debounce_ms` (120 ms).
  Momentary throttle-off dips spike the wheel-speed derivative past the threshold and
  clear within a tick or two; the debounce rejects them **without attenuating the
  signal**. This is deliberately a debounce and **not** a heavier low-pass filter: extra
  smoothing would suppress the same spikes only by delaying genuine hard-braking onset,
  which is the wrong trade for a safety light. Sustained braking still fires ≤ 120 ms
  later. On the [DE-07 40 mph ride log] it removed the last momentary `BRAKING` blips
  (8 → 3, transitions 48 → 30) at ~unchanged on-time; larger values began clipping real
  short brake taps, so 120 ms is the knee.
- **Stop-and-go:** creeping *past* `moving_speed_mph` drops `STOPPED → OFF`; the next
  gentle slowdown re-enters via rule 1/2. Sustained slow creep below the hysteresis band
  now holds the light rather than blinking.

[DE-07 40 mph ride log]: ../can-profiles.md#decode-table
- **Anti-strobe** is a global `state_min_dwell_ms` floor: no guard is evaluated until
  the floor has elapsed since the last transition. It is deliberately outside the
  guards, so the transition table stays about logic and not about flicker.

### Tunables

Defaults as shipped in `brake_fsm.h` (`BRAKE_TUNABLES_DEFAULT`), calibrated on the DE-07
ride logs through [`tools/trc_viz.html`](../../tools/trc_viz.html). Speeds in MPH,
accelerations in MPH/s. All are settable live with `state tune <name> <value>`, over the
same ranges as the bench viewer's sliders — except `decel_on_debounce_ms`, whose minimum
is one tick rather than zero, because a zero debounce degenerates into "on every tick".

| Tunable | Default | Purpose |
|---|---:|---|
| `decel_on_mphps` | 2.0 | Deceleration that turns the light **on** (rule 1). |
| `decel_on_debounce_ms` | 120 | ...held this long first. |
| `stop_speed_mph` | 1.0 | At/under = "stopped" (rules 2/3, rolling qualifier in 6b). |
| `moving_speed_mph` | 3.0 | Must be exceeded to leave `STOPPED` for motion (rule 6a). |
| `accel_off_mphps` | 0.5 | Acceleration that turns the light **off** (rule 4). |
| `accel_off_min_speed_mph` | 5.0 | ...only above this speed. |
| `steady_band_mphps` | 0.75 | \|accel\| under this counts as "steady" (rule 5). |
| `steady_timeout_ms` | 1500 | Steady-after-braking hold before turning off. |
| `stop_timeout_ms` | 60000 | Max on-time while stopped (rule 6c). |
| `state_min_dwell_ms` | 250 | Global anti-strobe floor. |
| `speed_smooth_ms` | 80 | Wheel-speed low-pass ahead of the slope (see §3). |

## 5. Firmware module/task decomposition
- **`brake_fsm.[ch]`** — the machine itself: the tunables struct, the three states, the
  hold timers, and one `brake_fsm_step(fsm, inputs, dt_ms)` call that advances it. Pure
  C, no ESP-IDF headers, no allocation, no clock of its own — it is handed `dt_ms`. That
  is what lets the identical code run on target at 50 Hz and on the host over a capture.
- **`brake_ctl.[ch]`** — the 50 Hz tick task on target: samples the decoded signals
  (`sig_snapshot`), maps them to FSM inputs (including the validity rules in §3), drives
  the brake-light output, and holds the `state force` override and the live tunables.
  All decision-shaped logic stays in `brake_fsm.c`; this is plumbing.
- **`can_decode.[ch]`** (DE-08) — supplies `speed_mph` and derives `accel_mphps`, per §3.
- **Reference implementation** — [`tools/trc_viz.py`](../../tools/trc_viz.py) and its
  in-browser twin [`tools/trc_viz.html`](../../tools/trc_viz.html): the same machine in
  Python/JS with every tunable on a slider, used to calibrate against ride captures.
- **Parity test** — [`tools/fsm_check.py`](../../tools/fsm_check.py) replays a capture
  through `test_host/fsm_replay` (the real `can_decode.c` + `brake_fsm.c`) and through
  the reference, and asserts **identical state at every tick**, plus agreement on the
  derived acceleration to 1e-3 mph/s. Runs in CI. This is what keeps the calibration
  bench and the shipping firmware the same machine; it is also what caught the
  ring-sizing defect in §3.

## 6. CLI hooks
- `sig set wheel <mph>`, `sig set clutch <0|1|na>`, `sig set gear <n|N>`,
  `sig set throttle`/`rpm` (for completeness); `sig source fake`; `sig ramp wheel
  <mph/s>` to drive a synthetic stop through the real derivation.
- `state show` — state, the inputs the last tick saw, the active timers, the emitted
  `brake_state_t`; `state force off|brake|auto`; `state tune [<name> <value>]` to sweep
  a threshold live. See [`cli.md`](../cli.md).

## 7. Isolation acceptance
- A synthetic decel ramp steeper than `decel_on_mphps` → `BRAKING` within budget; a
  gentle coast-to-stop → `STOPPED` via rule 2; reaching 0 from `BRAKING` → `STOPPED`
  (stays on).
- From `BRAKING`: a positive accel ramp above threshold (speed > 5 mph) → `OFF` (rule
  4); a held-steady speed → `OFF` after `steady_timeout_ms` (rule 5).
- From `STOPPED`: pulling away (speed > `moving_speed_mph`) → `OFF`; clutch released in
  gear **while rolling** (speed > `stop_speed_mph`) → `OFF`; neutral-with-clutch-out does
  **not** turn off until the `stop_timeout_ms` expires; the 60 s timeout fires.
- **Hysteresis:** a slow creep that stays between `stop_speed_mph` and `moving_speed_mph`
  in **neutral** holds `STOPPED` (no strobe); a standstill in gear with clutch out does
  **not** ping-pong `STOPPED`↔`OFF`.
- No transition violates the anti-strobe floor; the emitted `brake_state_t` matches the
  state map.
- **Signal loss:** `sig set wheel na` (or unplugging the bus) drops the light within a
  stale interval and leaves it off; restoring the signal behaves like a fresh start.
- **Against real rides:** `tools/fsm_check.py` over the DE-07 captures — tick-for-tick
  agreement with the reference, including the two captures with mid-ride wheel-speed
  dropouts, where the firmware holds the light off for the dark ticks and matches
  everywhere else.

## 8. Open items
- ~~Final tunable values and the acceleration smoothing window/filter.~~ **Resolved for
  now:** the table in [§4](#tunables) is what shipped, calibrated on the DE-07 logs in
  the bench viewer. Treat it as a starting point — it has not yet been ridden behind
  the real light.
- ~~Confirm `gear`/`neutral` and `wheel_speed` are actually decodable on the reference
  bus.~~ **Resolved in DE-07:** all present and decoded (see the golden test).
- **Not yet validated on the bike.** Every number above comes from replaying captures.
  The first on-road run with the light live is the real test, and the thing most likely
  to move is `decel_on_mphps`.
- ~~Stop-and-go flicker policy (a `STOPPED`→`OFF` hold/hysteresis vs. the literal
  rules).~~ **Resolved:** added `moving_speed_mph` hysteresis on the `STOPPED` exit +
  a rolling qualifier on the launch guard (see [§4 note](#4-state-machine)); validated on
  the DE-07 ride log (transitions 162 → 48). Final value (3.0 mph) still to confirm on
  more logs.
- Whether to ever use the reserved `ST_DECEL` tier for a softer coasting cue.

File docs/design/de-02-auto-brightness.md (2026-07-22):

# DE-02 — Auto-brightness

**Status:** 🔲 not started · **Device(s):** brake_light · **Depends on:** DE-00

Ambient-light-driven brightness for the LED bar: bright enough to be seen in daylight,
dim enough not to blind following traffic at night. A standalone safety feature,
testable with no radio link.

## 1. Scope & isolation boundary
- **In:** ambient-light sensing, ambient→brightness mapping, day/night scaling,
  user brightness cap, change smoothing → a single **commanded brightness** output.
- **Out (faked at edges):** ambient lux is injected with `ambient set`; the braking
  *state* is irrelevant here (test against a fixed `in set state`); actual LED driving
  is DE-04 — this element produces the brightness number and we read it via `render show`.
- **Isolation test:** brake_light board only; sweep faked lux, watch commanded brightness.

## 2. FFL traceability
BL-BRT-1…4.

## 3. Component selection
Ambient-light sensor (digital lux sensor over I²C, or analog photodiode + ADC) — see
[`hardware.md §2`](../hardware.md#2-brake_light-rider-side). Selection TBD.

## 4. I/O assignments & configuration
- Sensor bus/pin, sample rate (~5 Hz), lux range.
- Brightness curve (lux → 0–100 %), day/night breakpoints, cap, smoothing time-constant.
- **Physical endpoints** the 0–100 % maps onto come from the
  [LED brightness benchmark §4](../led-brightness-benchmark.md#4-design-target-for-the-helmet-bar):
  daylight peak ≈ **50–80 cd** on-axis (BRAKE) down to a night floor ≈ **5–15 cd**.

## 5. Firmware module/task decomposition
- Ambient task (~5 Hz): read sensor → map → smooth → publish `commanded_brightness`.
- Pure/host-testable: the lux→brightness curve, smoothing, and cap (no hardware).

## 6. CLI hooks
- `ambient show`, `ambient set <lux>`, `ambient source sensor|fake`, `bright cap`,
  `render show` (to read resulting brightness).

## 7. Isolation acceptance
- Faked daylight lux → near-cap brightness; faked darkness → low brightness; cap
  respected; transitions smoothed (no step/flicker) as lux jumps.

## 8. Open items
- Sensor choice and placement (must see ambient, not the bar's own glow).
- Curve/breakpoint values — calibrate against real day/night readings, anchored to the
  [benchmark](../led-brightness-benchmark.md) cd endpoints.

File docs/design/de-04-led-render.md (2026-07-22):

# DE-04 — LED render & bar driver

**Status:** 🟡 in design · **Device(s):** brake_light · **Depends on:** DE-00

Drives the main red brake bar: turns a braking **state** (`OFF`/`DECEL`/`BRAKE`) and a
**commanded brightness** (from [DE-02](de-02-auto-brightness.md)) into actual light, via
a constant-current LED driver. This element owns both the **render logic** (state +
brightness → a steady pattern and a current setpoint) and the **driver hardware**
(the boost CC stage that lights the string). It is the "actual LED driving" that
[DE-02 §1](de-02-auto-brightness.md) defers to.

## 1. Scope & isolation boundary
- **In:** the state→pattern map, the anti-strobe floor, the brightness→current/duty
  mapping, and the driver stage that converts a 1S Li-ion cell into a regulated LED current.
- **Out (faked at edges):** the braking *state* is injected with `in set state` (the
  real source is the link, DE-01/DE-03); the *commanded brightness* is injected with
  `ambient set` / `render` (the real source is DE-02); the **status-indicator** LED is a
  separate path ([DE-10](de-10-status-indicator.md)), not this element.
- **Isolation test:** brake_light board only; force each state × sweep brightness, watch
  the bar render correctly (steady, anti-strobe, current within limits) — no radio link
  or ambient sensor required.

## 2. FFL traceability
BL-RND-1…3 (state→pattern, steady-only/anti-strobe, dim running light) and
BL-LED-1…2 (drive the bar at commanded brightness via constant current; respect
thermal/current limits). Viewed through BL-CLI-4.

## 3. Component selection

### 3.1 Drive topology — series string + boost CC

The supply is a **1S Li-ion cell (18650 baseline): 3.0 V (cutoff) → 4.2 V (full)**,
~3.7 V nominal — the same electrical envelope as the earlier 1S LiPo, so the
topology analysis below is unchanged. A
high-brightness red LED has a forward voltage of **~2.0–2.5 V**, which sits *inside*
the battery range. That makes the per-LED count the real design lever:

| Series count | String Vf (≈) | vs. 4.2 V battery | Converter needed |
|---|---|---|---|
| 1× red | 2.0–2.5 V | always **below** | buck-boost (a plain boost can't step *down*) |
| 2× red | 4.0–5.0 V | marginal at top-of-charge | crossover zone → buck-boost / high-Vf parts |
| **≥3× red** | **6.0–7.5 V+** | always **above** | **plain boost — clean step-up headroom** |

So a **series string of ≥3 red LEDs**, driven by one **boost constant-current
regulator**, is the right topology: the string voltage is always above the battery (a
pure boost is valid across the entire discharge), one current loop sets every LED's
brightness identically, and a taller string at lower current keeps the boost's input
current — and conduction losses — down. A single string per CC loop guarantees matched
brightness with no ballast resistors.

This is also why a buck-boost part is *not* needed and would only add cost: we
deliberately choose the series count so we never enter the Vbatt-crosses-Vstring zone.

**Upper bound on series count.** The string voltage is bounded *above* by the driver's
output ceiling. With the down-selected mid-power emitters (§3.2, Vf ≈ 2.0–2.3 V),
**~8 in series ≈ 18 V** fits comfortably under our driver's 24 V ceiling with OVP
headroom; **10–12 in series (~21–26 V) does not**. So the emitter count the benchmark
calls for (~8–12 for an even bar) sets the layout: **≤ ~8 emitters → one series string**;
**more → two parallel series strings** (each ≤ ~8, with a small per-string ballast
resistor to share current, since mid-power reds are well Vf-matched), *or* step up to a
higher-V<sub>out</sub> driver (§3.3). This is the one place the
[brightness benchmark](../led-brightness-benchmark.md) and the driver choice must be
solved together — emitter count × Vf must clear the driver's V<sub>out</sub>.
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

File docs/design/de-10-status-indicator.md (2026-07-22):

# DE-10 — Status-indicator LED

**Status:** 🔲 not started · **Device(s):** brake_light · **Depends on:** DE-00

A **small dedicated indicator LED**, separate from the main brake-light array, that
reports device status and faults by **color and/or blink code**. The point is *discrete
diagnostics*: a rider (or bench tech) can read pairing, link, charge, and fault state
without leaning on the main bar — which may be off, dimmed, or itself the thing that's
broken. Maps naturally onto a single addressable RGB LED (WS2812-class), placed
**chip-down** on the brake_light PCB (`WS2812B-2020` / `WS2812B-Mini`) — the
brake_light now uses a **bare ESP32-C3-WROOM-02 module**, so the earlier "reuse a
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

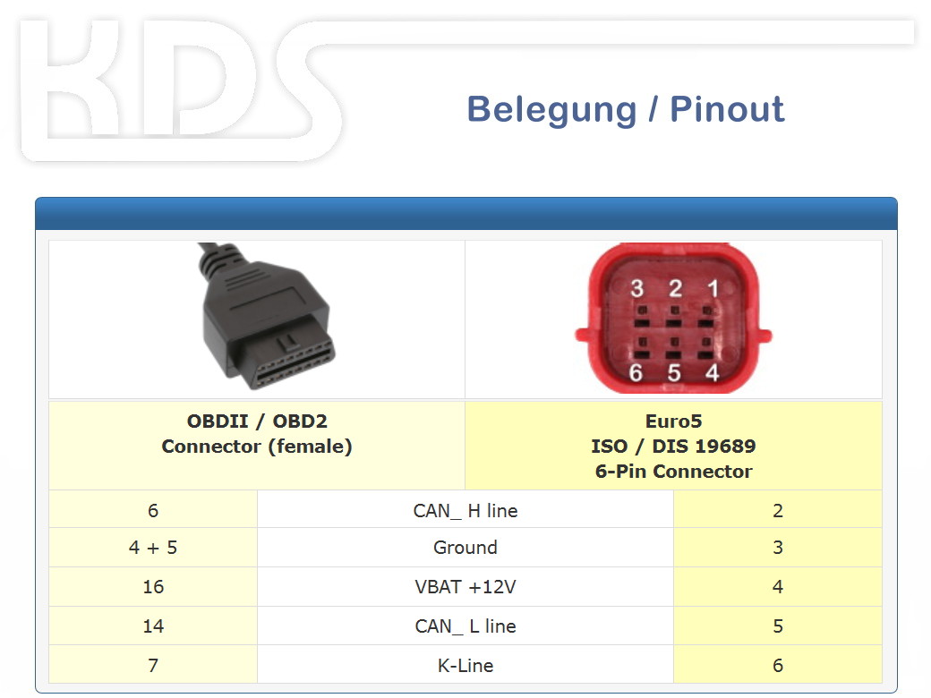
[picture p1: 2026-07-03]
transmitter/hardware/euro5.jpg

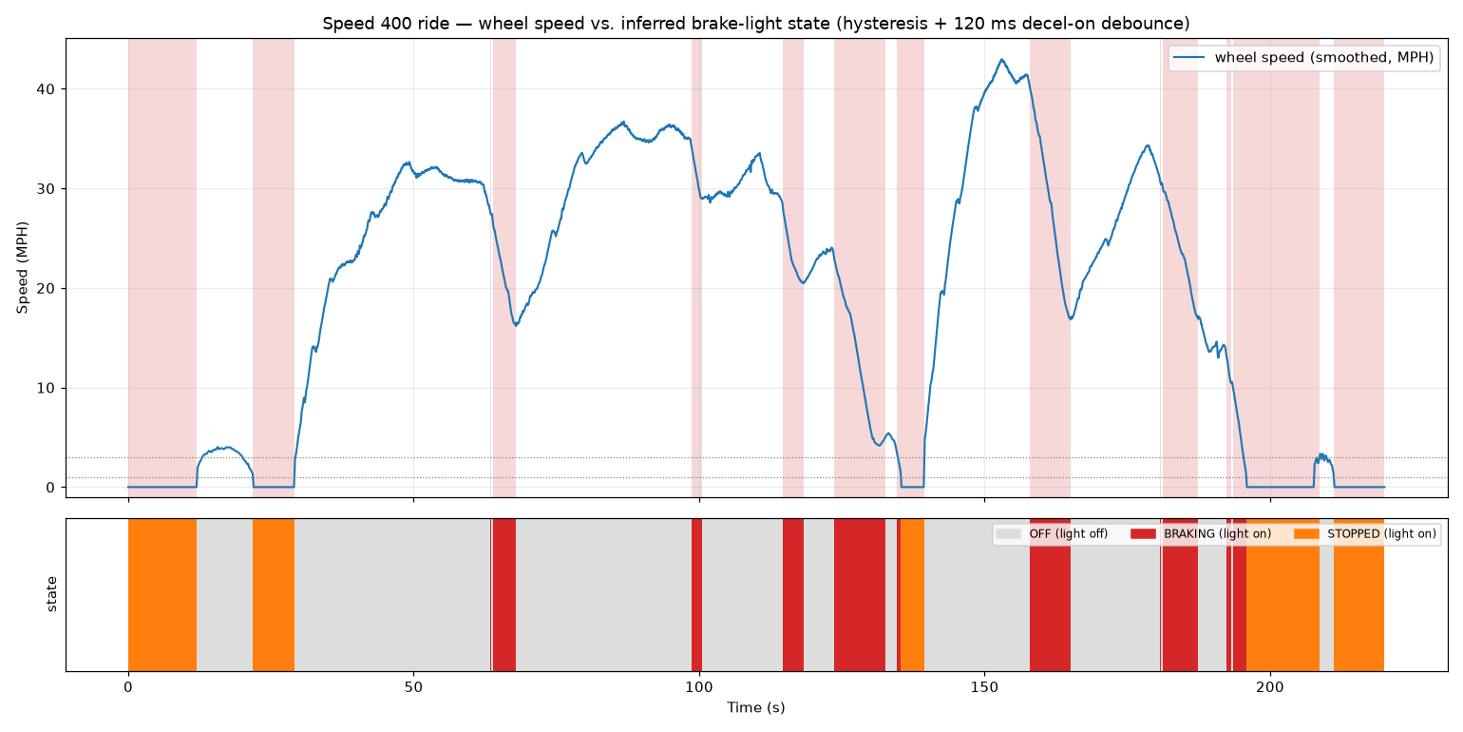
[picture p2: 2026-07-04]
logger/40mph_drive_cycle_fsm.png

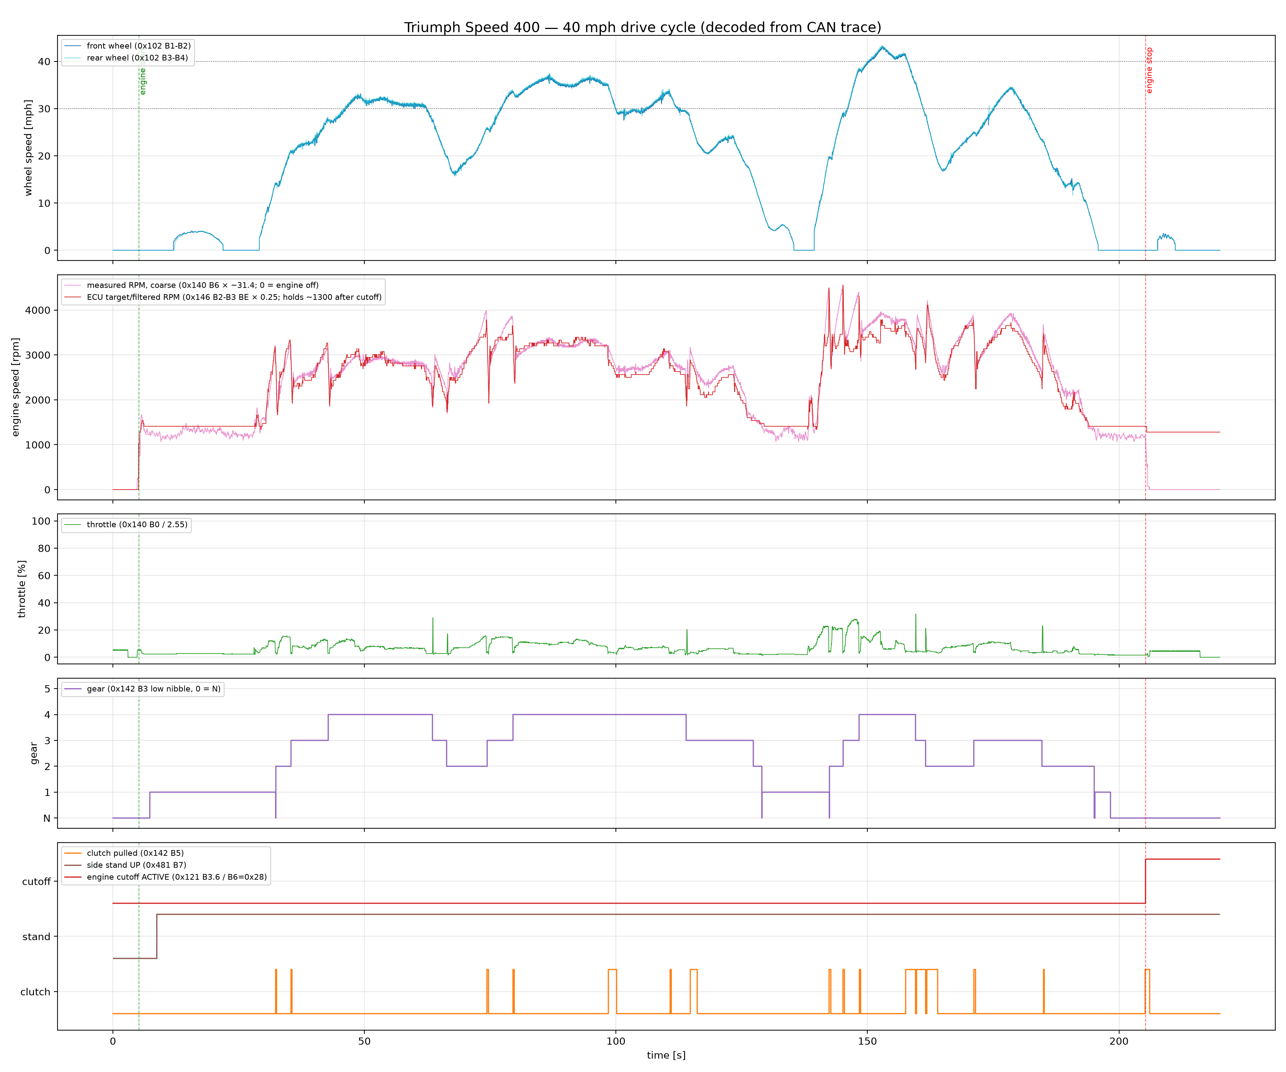
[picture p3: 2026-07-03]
logger/40mph_drive_cycle_decoded.png

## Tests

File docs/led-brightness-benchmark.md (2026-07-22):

# LED brightness & luminous-flux benchmark — brake_light bar

A sizing study: **how bright should the helmet brake bar be, and which LEDs do we design
in to get there?** We anchor on the lights this device imitates — automotive **CHMSLs**
(center high-mounted stop lamps, "third brake lights") — read off their regulated
intensity, adjust for the helmet context, convert to a luminous-flux budget, and
down-select an LED architecture.

This is cross-cutting hardware design context (like [`hardware.md`](hardware.md)
itself). It feeds two design elements:
- **DE-04 — LED pattern/render engine + driver** (`BL-LED-*`): the bar, emitter choice,
  and constant-current driver sized here.
- **DE-02 — [auto-brightness](design/de-02-auto-brightness.md)** (`BL-BRT-*`): the
  daylight peak and night floor below set the **endpoints** of the lux→brightness curve.

> Numbers below are of two kinds, kept distinct on purpose: **regulatory/product facts**
> (cited) and **derived design estimates** (with their assumptions stated). The estimates
> are first-pass sizing, to be confirmed with a photometer against a built bar — not a
> compliance claim. Open-CHMBL is an **auxiliary** light and makes **no** lamp-approval
> claim; see [`safety-regulatory.md`](safety-regulatory.md).

---

## 1. What we're imitating, and why the CHMSL is the right benchmark

A helmet brake light is, functionally, a **single central high-mounted red stop signal
that supplements the vehicle's main brake lamps** — which is exactly what an automotive
**CHMSL** is. So the CHMSL, not the primary stop lamp, is the correct photometric
benchmark:

- Like a CHMSL it is **supplementary**, not the legally-required primary stop lamp
  (the bike keeps its own — see [README](../README.md) and the safety doc).
- Like a CHMSL it sits **high and centered** in the following driver's field of view.
- Unlike a car CHMSL it sits **even higher** (~1.4–1.6 m, at/above a following car
  driver's eye line) and, in traffic, often **closer** — which *raises* the glare risk
  and makes night auto-dimming non-negotiable (§4, DE-02).

So we benchmark the **CHMSL band**, deliberately **not** the much brighter primary
stop-lamp band.

---

## 2. Regulatory benchmark — the intensity envelope (candela)

Stop signals are regulated in **luminous intensity (candela, cd)** on the reference
axis, not in lumens. The two regimes that matter:

| Lamp role | Standard | On-axis (H-V) intensity | Notes |
|---|---|---|---|
| **CHMSL** (3rd brake light) | **ECE R7**, cat. **S3/S4** | **min 25 cd, max 110 cd** | The supplementary high-mount signal. This is our anchor. |
| **CHMSL** (3rd brake light) | **FMVSS 108 / SAE J186** (US) | **≈ 25 cd** on-axis min; edge test points fall to ~16 cd and ~4 cd | Photometric *table* of points, not a single number; supplementary lamp. |
| Primary stop lamp | **ECE R7**, cat. **S1/S2** | **min 60 cd, max 260 cd** | The bike's *own* brake light class — **brighter** than a CHMSL by design. We do **not** target this. |
| Motorcycle stop lamp | ECE R50 / FMVSS 108 (m/c) | order of **tens of cd** (≈ 40 cd min class) | The bike's own rear stop; same "much brighter than a CHMSL is required to be" point. |

**Read-off:** the regulated envelope for a *high-mounted supplementary* red stop signal
is **≈ 25–110 cd on-axis** (ECE S3/S4), with US CHMSL minimums in the same ~25 cd range.
That band is the benchmark.

> ECE R7 explicitly *excludes motorcycles* from its scope, and Open-CHMBL claims no
> approval under it — we borrow its **CHMSL photometric band as a design target**, which
> is what makes the light recognizable as a brake signal to following traffic.

Sources: [49 CFR 571.108 (FMVSS 108)](https://www.law.cornell.edu/cfr/text/49/571.108) ·
[UNECE Regulation No. 7 (full text PDF)](https://www.unece.org/fileadmin/DAM/trans/main/wp29/wp29regs/2015/R007r6e.pdf) ·
[Dun-Bri guide to UNECE R7](https://www.dun-bri.com/Regulations-Standards/UNECE-Regulations/Guide-To-ECE-R7-Position-Tail-Stop-and-Clearance-Lamps) ·
[Daniel Stern Lighting — lighting codes](https://www.danielsternlighting.com/tech/lights/codes/codes.html).

---

## 3. Product benchmark — what real LED CHMSLs actually are

To sanity-check the intensity band against hardware reality:

| Datum | Value | Source |
|---|---|---|
| Incandescent CHMSL bulb (921) raw flux | **≈ 264 lm** — but emitted into 4π, most wasted in the housing; optics deliver only the ~25–80 cd that leaves the lens | product/TI |
| Typical OEM/aftermarket **LED CHMSL construction** | a **linear bar of ~6–16 mid-power red LEDs** behind reflector + lenticular optics, **constant-current** driven | [TI SSZT791 "CHMSL: the Third Brake Light"](https://www.ti.com/lit/ta/sszt791/sszt791.pdf) |
| LED CHMSL replacement **module flux** | **~170 lm** (modest) up to marketing-claimed **~1400 lm**; e.g. an [ORACLE linear CHMSL module](https://www.oraclelights.com/products/linear-universal-led-3rd-brake-light-chmsl-module-red) is **~6 W**, 12–24 V | product listings |
| LED CHMSL electrical power (typical) | **~1–3 W** for an OEM-style module | TI / product |

**Read-off:** real LED CHMSLs are a **handful of mid-power red LEDs, ~1–3 W**, and the
*module* flux that matters is small (~tens to low-hundreds of lumens) because optics
concentrate it into the regulated cone. Brute-force lumens are **not** how a CHMSL is
built — beam shaping is. That directly informs the down-select (§5).

---

## 4. Design target for the helmet bar

Combining §2 (intensity band) and §4-context (helmet sits higher/closer, battery-powered,
auto-dimmed):

| Quantity | Design target | Rationale |
|---|---|---|
| **Daylight peak on-axis intensity** (BRAKE) | **≈ 50–80 cd** | Mid-to-upper of the ECE S3/S4 CHMSL band (25–110 cd). Enough to read as a brake signal in sun; not into primary-stop-lamp territory. |
| **Night floor on-axis intensity** (BRAKE) | **≈ 5–15 cd** | Still clearly "on/brake" at night without dazzling a close follower. Sets DE-02's dark-end. |
| **DECEL state** | **~30–50 %** of the current BRAKE level | Soft secondary cue; never brighter than BRAKE (see [ARCHITECTURE §4](../ARCHITECTURE.md#4-braking-state-machine)). |
| **OFF / running light** (optional) | **≈ 1–3 cd** | Dim presence marker only. |
| **Strobe** | **none** | Steady only; anti-strobe floor (`BL-RND-2`). |

We deliberately target the **CHMSL band, auto-dimmed**, rather than maxing out: it's
auxiliary, it's close to following eyes, and every lumen costs runtime (§6).

### 4.1 Candela → luminous-flux budget (so we can spec LEDs in lumens)

LEDs are sold in **lumens (Φ)**, not candela, so we convert through the beam solid angle:
**Φ ≈ I_peak × Ω_eff**.

**Beam assumption (design choice):** a helmet light must be read across lanes and at
varying follow distances and rider head positions, so we spread wider than a car CHMSL —
target a main lobe of about **±40° horizontal × ±12° vertical** (full 80° × 24°).

- Geometric solid angle ≈ (80°=1.40 rad) × (24°=0.42 rad) ≈ **0.59 sr**; peak-weighted
  effective ≈ **0.4–0.5 sr**.
- Directed flux at the daylight peak: Φ ≈ 65 cd × ~0.45 sr ≈ **~30 lm into the main
  lobe** → call it **≈ 25–50 lm of *directed* red flux** at full brightness.
- Account for optics + off-axis spill + thermal derating (η ≈ 0.5–0.7): required
  **raw LED-level red flux ≈ 40–90 lm**.

**Design point:** build in **≈ 60–100 lm of installed red LED capability**, and run it
**well below maximum** in normal use. That gives daylight headroom, thermal margin, and a
long-lived array that idles cool — and night/idle states drop to a few lumens.

> Sensitivity: these flux figures scale directly with the assumed beam width. A tighter
> beam (more like a car CHMSL, ±20°×±8°) needs **less** flux for the same cd but is less
> forgiving of head/lane position; a wider wash needs more. Confirm Ω with the chosen
> optic/diffuser, then re-derive. The **intensity** targets in §4 are the firm ones.

---

## 5. LED down-select

### 5.1 Color / wavelength
Red, **620–630 nm** (the automotive "stop red" band). This is where red luminous
efficacy is high and the color reads unambiguously as a brake signal. **Avoid deep red
(≈ 660 nm)** horticulture/IR-adjacent emitters: they look dim per watt to the eye and
sit at the edge of/outside the legal stop-red region. A red emitter (not a white LED
behind a red lens) is also the simplest legal-color story — matching the lean already in
[`hardware.md §2`](hardware.md#2-brake_light-rider-side).

### 5.2 Architecture trade — three candidates

| Architecture | Hit 60–100 lm by | For | Against | Verdict |
|---|---|-----|---|---|
| **Mid-power red array** (2835/3030, ~6–12 emitters) | many low-driven emitters, ~20–40 lm each @ 60–100 mA, Vf ~2.0–2.3 V | **Even bar look**; low current per emitter; **redundancy / graceful degradation**; cheap; LCSC-sourceable; trivial constant-current driver; runs cool below rated → long life + daylight headroom | needs a (simple) CC driver and a diffuser | ✅ **Recommended** |
| **High-power emitters** (2–4 × Cree XP-E2 Red / OSRAM Oslon, ~70–90 lm @ 350 mA) | a few bright nodes + secondary optics | fewest parts; compact | hotspots / uneven bar; needs real optics + heatsinking on a helmet; higher per-node current; harder to keep low-profile & cool | ➖ Possible for a compact spot, worse for an even helmet bar |
| **Addressable RGB (WS2812-class) as the bar** | ~50–100 pixels at full red | per-pixel patterns | red die ≈ **1–2 lm each** (indicator-grade, hundreds of mcd) → need **dozens–hundreds** + **~1–2 A** to reach the flux target; expensive; RGB-white-die red is a weak, slightly-off stop color | ❌ **Rejected for the bar** |

**The addressable-vs-discrete open question is resolved by the flux math:** WS2812-class
parts are display/indicator emitters (~1–2 lm of red apiece), so meeting a CHMSL-class
**60–100 lm of red** would take dozens to hundreds of them and on the order of an amp —
absurd next to a handful of mid-power reds. Addressable RGB therefore stays exactly where
the architecture already puts it: the **[status indicator](design/de-10-status-indicator.md)
(DE-10/`BL-IND`)**, **not** the brake bar. The bar is **discrete 620–630 nm red on a
constant-current driver**.

### 5.3 Concrete emitter candidates (design-in shortlist)
Mid-power 2835/3030 red, 620–630 nm — verify the live datasheet (flux bin, Vf, thermal
derating) before committing, and prefer LCSC-stocked parts to match the BOM philosophy in
[`hardware.md §2.1`](hardware.md#21-integrated-module-candidates-ws2812--lipo-charger):

- **OSRAM** SYNIOS P2720 / TOPLED red (automotive-grade, 620–630 nm).
- **Cree** JSeries 2835 red.
- **Everlight / Lite-On / generic** 2835 red, ~625 nm, ~28–34 lm @ 60 mA, Vf ~2.0–2.2 V
  (the cheap, LCSC-clean baseline).

**Indicative array:** **~8–12** such emitters. At ~30 lm/emitter rated they total ~240–360
lm of *capacity*, so the bar delivers the **60–100 lm** target while each emitter runs at
**a fraction of its rated current** — cool, efficient, redundant, with plenty of daylight
headroom and lots of dimming range for DE-02. Final count follows the chosen optic/diffuser
and bar length.

---

## 6. Power & runtime cross-check (closes the loop with `hardware.md`)

At the **60–100 lm** raw-red design point and a driven-red wall-plug efficacy of
~**50–100 lm/W**, the bar draws **≈ 0.6–2 W** at the **daylight BRAKE peak** → on a
~3.3–3.7 V rail, roughly **0.2–0.6 A peak**. But:

- BRAKE events are **brief**; OFF/DECEL/night states sit far lower (a few lm, tens of mA).
- DE-02 **auto-dim** pulls the *average* down hard.

So the **average** LED draw stays in line with the **~120 mA** already assumed in the
[`hardware.md` runtime worked example](hardware.md#runtime-budgeting-worked-example), and
the **1500 mAh / ~8.5 h** full-day target holds. This benchmark **sizes the peak and the
emitter**; it doesn't blow the runtime budget. If a brighter beam is chosen later, re-run
that worked example — peak daylight BRAKE is the worst case for both glare and current.

---

## 7. Outputs / what this pins down

- **Intensity target:** daylight BRAKE **≈ 50–80 cd** on-axis; night floor **≈ 5–15 cd**
  → the endpoints of the DE-02 brightness curve.
- **Flux budget:** **≈ 60–100 lm** of installed 620–630 nm red LED capability, run below
  max.
- **Architecture:** **discrete mid-power red 2835/3030 array (~8–12 emitters) on a
  constant-current driver** — resolves the `hardware.md §3` "addressable vs. discrete"
  open question in favor of discrete red; addressable RGB is **status-indicator only**.
- **Feeds:** DE-04 (`BL-LED-*`) emitter/driver design; DE-02 (`BL-BRT-*`) curve endpoints.

## 8. Open items
- Confirm beam solid angle with the actual optic/diffuser, then re-derive the flux budget
  (§4.1 is beam-width-sensitive).
- Pick the final emitter part + bin and bar length / emitter count against it.
- Bench-verify on-axis cd and the day/night dim endpoints with a photometer on a built
  bar (this study is sizing, not a measurement).
- Thermal: confirm the chosen emitters stay within derating at the daylight peak inside a
  sealed IP65+ enclosure on a helmet.
</content>
</invoke>

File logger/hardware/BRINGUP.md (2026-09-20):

# Logger PCB — bring-up plan

Board bring-up for the custom **ESP32-S3-WROOM-1-N4** CAN logger
([`logger.kicad_sch`](logger.kicad_sch) / [`logger.kicad_pcb`](logger.kicad_pcb)).
Target reader: experienced embedded engineer. Each section is a self-contained gate —
finish and sign it off before moving to the next. Work USB-powered on the bench until
§8; keep the bike 12 V path out of it until the low-voltage side is proven.

> **Status column:** every step table carries one. `✅ <date>` = verified on hardware ·
> `◐ <date>` = partially verified, see the notes under that table · `⚠→✅` / `⚠→◐` =
> failed first, passed after a rework — **read the note under that table before trusting
> the result** · `—` = not yet run · `n/a` = optional/skipped. Dates are the board this
> plan tracks (MAC `ac:27:6e:c2:c9:38`); re-run from scratch for a new board.

> **⚠ This board carries a rework: U3 (USB ESD protection) is removed.** See §2. It is
> not as-designed, and §10 cannot be signed off until U3 is replaced and §2 re-run.

> **Firmware approach:** the logger app in [`../software/`](../software) **is now
> ported** to this board — target `esp32s3`, the §0 pin map, `CONFIG_SPIRAM` dropped,
> 4 MB flash, native-USB console, and a three-LED indicator (external IO18 + D5/D6)
> replacing the WROVER-KIT's single red die. Backwards compatibility with the
> WROVER-KIT was explicitly dropped. It builds clean; **everything below marked `—`
> is still unverified on hardware.**
>
> Two things the port carries that bring-up should lean on: the CAN silent pin (IO35)
> is parked **high-impedance and read back at boot**, with a loud console warning if
> it is not high (that is §4.2 answered from the chip side), and *microSD → SDMMC bus
> width* is Kconfig-selectable 1-bit/4-bit with the negotiated width printed at mount,
> which is exactly the §6.2 → §6.3 progression.
>
> **Still outstanding:** the Kconfig-gated **self-test mode** described in the original
> plan — a console command or boot-time button hold that walks each peripheral in turn
> — was **not** built. The §4/§5/§6 steps that name it should be read as "exercise this
> with the ported firmware", using the boot log and the LEDs, or with a scratch app in
> [`../software/bringup/`](../software/bringup/).

---

## 0. As-built pin map (from netlist)

Verified against the exported KiCad netlist of the committed schematic. Use this, not
the older `logger_sch_revA.pdf` and not the README GPIO references.

| Signal | GPIO | U1 pin | Net / notes |
|---|:----:|:---:|---|
| CAN TXD | **IO21** | 23 | → U2 (TCAN330) pin1 TXD; `R15` pull-up to 3V3 |
| CAN RXD | **IO47** | 24 | ← U2 pin4 RXD |
| CAN S (silent) | **IO35** | 28 | → U2 pin8 S; `R16` pull-up to 3V3 → **defaults silent** |
| SD CLK | **IO9** | 17 | J5 pin5 via series `R12` |
| SD CMD | **IO10** | 18 | J5 pin3; `R9` pull-up |
| SD DAT0 | **IO48** | 25 | J5 pin7; `R10` pull-up |
| SD DAT1 | **IO17** | 10 | J5 pin8; `R11` pull-up |
| SD DAT2 | **IO12** | 20 | J5 pin1; `R7` pull-up |
| SD DAT3/CD | **IO11** | 19 | J5 pin2; `R8` pull-up |
| SD card-detect (DET_A) | **IO8** | 12 | J5 pin10; `R17` pull-up, active-low |
| Button (BTN_SIG) | **IO6** | 6 | J4 pin3; `R5` pull-up, **active-low** |
| Ext LED drive | **IO18** | 11 | Q1 (2N7002K) gate via `R3`; `R18` gate pull-down; low-side to J4 pin2 |
| Status LED D5 | **IO2** | 38 | via `R20`, active-high |
| Status LED D6 | **IO1** | 39 | via `R21`, active-high |
| USB D− / D+ | — | 13 / 14 | J2; ESD via U3 (USBLC6-2P6). **Native USB**, no UART bridge |
| UART0 TX / RX (console TPs) | GPIO43 / 44 | 37 / 36 | `TP2` / `TP1` — boot-ROM log at 115200 |
| EN / reset | — | 3 | `SW1`, `R13` pull-up, `C9` |
| BOOT (IO0) | IO0 | 27 | `SW2` to GND (download mode) |

> **Strapping status (this rev is clean):** IO0 = boot button (internal PU),
> IO45 = **unconnected** (internal PD → 3.3 V flash, correct), IO46 = unconnected,
> IO3 = unconnected. The `hardware/README.md §5` "GPIO45 silent-pin" issue **no longer
> applies** — S was moved to the non-strapping IO35. Confirm in §4 anyway.

---

## 1. Pre-power inspection

**Objective:** catch assembly defects and rail shorts before any power is applied.

| # | Step | Status |
|---|---|:---:|
| 1 | Inspect U1, U2, U3, U4 under magnification: orientation (pin-1), solder bridges, tombstoning, missing parts vs. BOM. | ✅ 07-26 |
| 2 | Confirm D4 (20CJQ060) and D3 (SM24CANB TVS) orientation; confirm C1–C9 populated. | ✅ 07-26 |
| 3 | DMM continuity, power OFF: check **+3V3 → GND**, **+5VD → GND**, and **VBUS → GND** are each **not** a dead short. | ✅ 07-26 |
| 4 | Confirm GND continuity across J2 shell, J3 pin4, J4 pin1, J5 GND, U1 pad. | ✅ 07-26 |
| 5 | Ohm out `R16` (IO35↔3V3) and `R15` (IO21↔3V3) present; confirm IO45 has **no** stuffed pull-up (validates the silent-pin rework). | ✅ 07-26 |
| 6 | Verify J5 (microSD) socket seating and that DET_A (`R17`) pull-up is present. | ✅ 07-26 |

> **§1 complete — all six steps passed, manual inspection 2026-07-26.** No assembly
> defects, no rail shorts. Step 5 clears the silent-pin rework at the board level
> (`R16`/`R15` present, IO45 pull-up unstuffed), which §3/§4.3 later corroborated from
> the chip side via esptool's 3.3 V flash-voltage report.

---

## 2. Power rails (USB-C bench power)

**Objective:** bring up +5VD and +3V3 from USB-C only, current-limited, before the MCU is trusted.

| # | Step | Status |
|---|---|:---:|
| 1 | Bench supply or USB with current limit ~150 mA. Apply USB-C to J2. Watch inrush; a hard limit trip = short → stop. | ⚠→✅ |
| 2 | Measure **+5VD** ≈ 5 V (one Schottky drop below VBUS is expected only on the 12 V path, not USB VBUS). | ⚠→✅ |
| 3 | Measure **+3V3** = 3.3 V ±3% at U4 output / L1 / a 3V3 test point. Check ripple on scope (< ~30 mVpp). | ⚠→◐ |
| 4 | Thermal check: U4 (TPS62172) and U1 not hot after 1 min at idle. | — |
| 5 | Confirm CC1/CC2 5.1 kΩ pull-downs present (UFP sink) — host should supply 5 V without negotiation. | — |
| 6 | Remove power; raise supply limit to ~500 mA for subsequent sections. | — |

> ### ⚠ 2.1–2.3 FAILED on first attempt — U3 destroyed, and **U3 is now depopulated**
>
> **Timeline:** first power application **2026-07-26** (USB-C, supply limited to 150 mA)
> tripped the limit — a **soft short from VBUS to GND**, present **only under power**;
> an unpowered DMM check was clean, which is why §1.3 passed. Fault bisected to
> **U3 (USBLC6-2P6)**. Board left unpowered until hot air was available; **U3 removed
> 2026-08-03**, which cleared the short, and 2.1–2.3 passed the same day. Applying power
> appears to have damaged U3.
>
> **The board this plan tracks is therefore NOT as-designed: U3 is absent, so J2's
> `D+`/`D−` have no ESD protection.** Handle the USB port accordingly, and do not sign
> off §10 until U3 is replaced and §2 re-run on the reworked board.
>
> *To confirm:* the §3/§4 results are also dated 2026-08-03, the same day as the rework,
> so whether they were taken before or after U3 came off is not recorded. It does not
> change any of those results — the fault was a supply-side leakage that a
> current-limited bench supply caught and a normal USB host would likely have sourced
> through — but note it if the §3/§4 numbers ever need to be attributed precisely.
>
> **Root cause not established.** A "short only when biased" is the signature of a
> damaged junction, and it fits a defective, ESD-damaged, or reflow-damaged part. It is
> **not** explained by overvoltage on the clamp pin: U3 pin 5 (VBUS, 5.25 V max, VBR
> min 6.0 V) sits on `+5VD`, and `+5VD` is **USB VBUS only** — D4 is a common-cathode
> dual Schottky whose shared cathode (pin 2) is the *regulator input* node, so the
> 12 V path ORs in there and the `+5VD`-side diode reverse-biases. 12 V never reaches
> `+5VD` or U3. Worth checking on the replacement: correct part (LCSC `C15999`), pin-1
> orientation, and ESD handling during rework.
>
> **Open gap:** steps **2.4–2.6** (thermals, CC pull-downs, raise the current limit)
> were never reported either way — marked `—` rather than assumed. They will need doing
> on the reworked board regardless, once U3 is replaced.
>
> **2.3 partial:** board VCC measured **3.24 V** on USB power — in spec (3.3 V −1.8%).
> Ripple not yet scoped, and this was a spot DMM reading rather than a measurement at
> U4 output / L1 / a labelled 3V3 test point. Re-take properly to close the step.

---

## 3. USB enumeration, boot & flash

**Objective:** prove native-USB, boot strapping, and the flash/console path.

| # | Step | Status |
|---|---|:---:|
| 1 | Connect J2 to host. Confirm the ESP32-S3 USB-serial-JTAG device enumerates (`lsusb` / dmesg / Device Manager). | ✅ 08-03 |
| 2 | Optionally attach a scope/UART to `TP2` (GPIO43, 115200) and confirm second-stage boot-ROM log on reset (`SW1`). | n/a |
| 3 | Enter download mode: hold `SW2` (BOOT), tap `SW1` (EN), release `SW2`. Run `esptool.py chip_id` / `flash_id`. | ◐ 08-03 |
| 4 | Confirm chip = ESP32-S3, flash = **4 MB**, **PSRAM = none** (matches `-N4`). A flash-read error here points at strapping/IO45 — recheck §1.5. | ✅ 08-03 |
| 5 | Bring up the `esp32s3` firmware skeleton (target set, pin map stubbed, `CONFIG_SPIRAM` dropped); confirm it boots from normal boot (no `SW2` held) and its console log prints over native USB. | ✅ 08-03 |
| 6 | Confirm auto-reset-to-download works from the flasher (DTR/RTS via native USB) so later steps don't need the button dance. | ✅ 08-03 |

> **Build firmware for 4 MB (`CONFIG_ESPTOOLPY_FLASHSIZE_4MB`).** U1 is an
> `ESP32-S3-WROOM-1-N4` per the schematic and production BOM (LCSC `C2913197`):
> **4 MB flash, no PSRAM.** Confirmed on the bench — `esptool.py flash_id` reports
> JEDEC `c8`/`4016` = GigaDevice GD25Q32, 32 Mbit.
>
> Build for 8 MB by mistake and the app boot-loops before `app_main`, with
> `E spi_flash: Detected size(4096k) smaller than the size in the binary image
> header(8192k)` followed by `assert failed: __esp_system_init_fn_init_flash
> startup_funcs.c:114`. **The 2nd-stage bootloader prints `SPI Flash Size : 8MB`
> on the way up in that case** — that echoes the image header, not a probe of the
> part, so it is not evidence about the fitted flash. Only the runtime probe and
> `flash_id` are. Plan partition sizing and any OTA headroom against 4 MB.

**As-built results:** USB-serial-JTAG enumerates as `/dev/cu.usbmodem101`; chip =
ESP32-S3 (QFN56) rev v0.2, no PSRAM; flash = 4 MB (matches `-N4`); esptool reports
*"Flash voltage set by a strapping pin to 3.3V"*, which independently clears the §1.5 /
§4.3 IO45 concern.

> **3.5 pass, via the scratch app — the logger port itself is still outstanding.**
> Verified in [`../software/bringup/blink/`](../software/bringup/blink/):
> `CONFIG_IDF_TARGET="esp32s3"`; **no `CONFIG_SPIRAM`** (the option is absent entirely,
> not merely unset — correct for a module with no PSRAM); pin map stubbed to the §0
> assignments (IO1/IO2/IO8); console on `CONFIG_ESP_CONSOLE_USB_SERIAL_JTAG` with the
> UART console disabled (`CONFIG_ESP_CONSOLE_UART_NUM=-1`), and logs read back over
> native USB throughout §4; boots from normal boot with `SW2` never touched, 20/20
> across the §4.3 soak.
>
> That satisfies everything this step asks for, but note **what it is**: a scratch app,
> not the logger firmware. The port the firmware-approach note calls for — real app on
> `esp32s3`, two-LED status indicator, self-test mode — is unchanged and still tracked
> in §10. This step proves the *board* runs an `esp32s3` build; it does not mean the
> port is done.

> **3.3 partial:** `chip_id` and `flash_id` both ran clean, but via **auto-reset**, not
> the documented `SW2`/`SW1` button dance — the manual path is still unproven. Step 6
> makes that acceptable in practice (auto-reset works over native USB, no dance needed),
> but do the button sequence once if `SW1`/`SW2` are to be considered tested.
>
> **3.2 skipped:** step is marked optional and the native-USB console served the same
> purpose. `TP1`/`TP2` remain unverified.

---

## 4. GPIO & strapping verification

**Objective:** confirm strapping pins settle correctly and the silent-pin rework is real on this board.

| # | Step | Status |
|---|---|:---:|
| 1 | Via the firmware's self-test mode, toggle status LEDs on **IO2 (D5)** and **IO1 (D6)**; confirm each lights (active-high). Wire these into the ported status-indicator module as you go. | ✅ 08-03 |
| 2 | Read **IO35** at reset (before driving it): scope/logic-probe should show it **high** (R16 pull-up) — this is the CAN-silent default, now on a non-strapping pin. | — |
| 3 | Confirm IO45 floats near 0 V at boot (internal PD) and the board boots repeatably across ~10 EN resets — no intermittent flash errors. | ✅ 08-03 |
| 4 | Read **BTN_SIG (IO6)**: high at idle (R5), goes low when J4 pin3 is shorted to GND. | — |
| 5 | Read **DET_A (IO8)**: high with no card, low with a card seated in J5. | ✅ 08-03 |

> **4.1 pass:** both LEDs light active-high. The test pattern drives red alone, then
> green alone, before alternating — so it also confirms IO1/IO2 are **not swapped**
> relative to the §0 netlist map, which a simultaneous blink could not distinguish.
> Done with the scratch app [`../software/bringup/blink/`](../software/bringup/blink/),
> **not** the self-test mode. The IO1/IO2 assignments this step confirmed are now
> carried in the ported firmware's indicator module (`status_led.[ch]`), which also
> drives the external LED on IO18 — that third LED is **not** covered by this step and
> is still §7.2.
>
> **4.5 pass:** IO8 reads **high with J5 empty** and **low with a card seated**, and
> transitions cleanly on insert/remove at runtime. Read with the **internal pull-up
> disabled**, so the high state is `R17` doing the work — an internal pull would have
> read high even with R17 missing and turned a real failure into a false pass. Scratch
> app [`../software/bringup/blink/`](../software/bringup/blink/) prints the level at boot
> and on every change.
>
> **4.3 pass:** two halves, both covered.
>
> *Strapping:* esptool reports *"Flash voltage set by a strapping pin to 3.3V"* — the
> fact the step is after, read from the chip rather than probed at the pin.
>
> *Repeatability:* **20/20 clean boots**, scripted via
> [`../software/bringup/reset_soak.py`](../software/bringup/reset_soak.py) — twice the
> ~10 the step asks for. Every cycle was a genuine reboot (`rst=USB`, uptime back to
> 507 ms), with no error logs, asserts or reboot loops. A chip reset re-runs the boot
> ROM, re-samples strapping and re-reads flash, so intermittent flash or strapping
> faults would have surfaced.
>
> **Caveat — SW1 and the EN RC network are still untested.** The soak commands resets
> over USB rather than pulling the EN pin, so `SW1`/`R13`/`C9` are not exercised. That
> gap is tracked in the §3.3 note; press SW1 by hand a few times to close it.
>
> **Two traps the script documents, both of which silently produce wrong results:**
> `USBJTAGSerialReset` is the *enter-download-mode* sequence (it drives IO0 low and
> parks the board in the ROM bootloader — it does not restart the app), and pyserial
> asserts DTR on open, which stops the USB-JTAG peripheral acting on `HardReset`'s RTS
> pulse. Either one leaves the board simply running on, which is why the script proves
> each reboot from a *fresh uptime* rather than assuming the reset worked.

---

## 5. CAN transceiver (U2 TCAN330)

**Objective:** prove TWAI ↔ TCAN330 path and hardware silent-mode control, listen-only first.

| # | Step | Status |
|---|---|:---:|
| 1 | Drive **IO35 low** from firmware (S = normal mode) only after §5.3; leave default (high/silent) for the first powered check. | — |
| 2 | TWAI self-test / loopback via the firmware's self-test mode (`esp32s3`, IO21 TX / IO47 RX): confirm the controller reaches error-active and frames loop back internally. | — |
| 3 | Connect J3 CAN-H/CAN-L to a known 500 kbit/s bus (PCAN-USB or second node) with proper termination. Keep **listen-only** (S high). | — |
| 4 | Confirm frames are received and timestamped; verify **no ACK / no TX** on the bus with a scope on CAN-H (golden-rule listen-only). | — |
| 5 | Only on an isolated bench bus: drive IO35 low, send a frame, confirm normal-mode TX works and TCAN330 sources a dominant bit. | — |
| 6 | Scope CAN-H/CAN-L differential for clean levels (~2.5 V recessive, ~1 V diff dominant); confirm D3 TVS not clamping under normal signaling. | — |

---

## 6. microSD (SDMMC 4-bit)

**Objective:** prove the full 4-bit SDMMC bus that drove the S3 choice.

| # | Step | Status |
|---|---|:---:|
| 1 | Insert a known-good card. Confirm DET_A (IO8) reads inserted (§4.5). | ◐ 08-03 |
| 2 | Mount 1-bit SDMMC first (CLK IO9, CMD IO10, DAT0 IO48); confirm init, CID/CSD read, capacity correct. | — |
| 3 | Switch to **4-bit** (add DAT1 IO17, DAT2 IO12, DAT3 IO11); confirm mount and error-free init. | — |
| 4 | Sequential write/read a multi-MB file, CRC-verify. Push clock to the intended rate; watch for CRC/timeout errors indicating SI issues on DAT lines. | — |
| 5 | Sustained-write throughput test at target bitrate-equivalent load; confirm no overruns (this is the capture-path bottleneck). | — |
| 6 | Card insert/remove cycling: confirm DET_A transitions and no bus lock-up. | ◐ 08-03 |

> **6.1 / 6.6 partial — the DET_A half only.** §4.5 already showed IO8 reading inserted
> and transitioning cleanly on insert/remove, so the detect side of both steps is done.
> What is **not** done: 6.1's card is not yet proven *known-good* (nothing has mounted
> it), and 6.6's "no bus lock-up" is unassessable until the SDMMC bus is actually
> running. Re-run both once §6.2 mounts a card — do not treat these as cleared.

---

## 7. Button & LEDs (J4)

**Objective:** validate the operator control breakout.

| # | Step | Status |
|---|---|:---:|
| 1 | On J4: pin1 GND, pin2 LED drive, pin3 BTN_SIG, pin4 +3V3. Confirm 3V3 present on pin4. | — |
| 2 | Wire an external LED (pin4 → LED → pin2). Drive **IO18 high**; confirm Q1 sinks and LED lights; low = off. Check R4 sets sane current. | — |
| 3 | Wire a button (pin3 → button → pin1/GND). Confirm debounced active-low reads on IO6. | — |
| 4 | Confirm D1/D2 TVS on the J4 signal lines don't distort BTN_SIG logic levels. | — |

> Note: §7 covers the **external** LED on J4 via Q1 (IO18). The **onboard** status LEDs
> D5/D6 are §4.1 and are already passing — the two are independent circuits.

---

## 8. Bike 12 V power path

**Objective:** validate the automotive input, diode-OR, and reverse-polarity protection — last, and deliberately.

> Standard (non-automotive) buck and a Schottky for reverse protection — **bench/ride
> use only**, not a permanent bike install (per README §2). No load-dump clamp here.

> **Rail topology (read before probing).** `+5VD` is **not** a regulated 5 V rail and is
> **not** the 12 V path: it is J2's USB VBUS net (`J2` A4/A9/B4/B9), and it also carries
> U3 pin 5. **D4 (20CJQ060) is a common-cathode dual Schottky** — anodes on `+12P`
> (pin 1) and `+5VD` (pin 3), **shared cathode on pin 2**, which is the U4 (TPS62172)
> input node. So the two supplies OR together *at D4 pin 2*, not on `+5VD`; on 12 V-only
> power `+5VD` sits near 0 V and its diode blocks backfeed toward USB. That reverse-bias
> is what §8.3 is testing.

| # | Step | Status |
|---|---|:---:|
| 1 | Bench supply to J3 pin3 (+12 V) / pin4 (GND), current-limited. Confirm the **U4 input node** (D4 pin 2, common cathode) ≈ 12 V − Vf(D4), and that **`+5VD` stays at ~0 V** with USB unplugged — the `+5VD`-side diode must reverse-bias. Verify +3V3 = 3.3 V. | — |
| 2 | **Reverse-polarity test:** swap J3 +12/GND; confirm D4 blocks, no current flows, rails stay at 0, no damage. | — |
| 3 | Diode-OR test: power both USB-C and 12 V; confirm no backfeed from +5VD onto J3 pin3 and no USB VBUS onto the 12 V harness. | — |
| 4 | Sweep input 9–15 V; confirm +3V3 stays in regulation and U4 thermals are acceptable. | — |
| 5 | CAN TVS (D3) sanity: confirm normal CAN signaling on the 12 V-powered board is unaffected. | — |

---

## 9. Integration & soak

**Objective:** confirm the whole capture chain end-to-end under realistic load.

| # | Step | Status |
|---|---|:---:|
| 1 | Run the fully-ported logger firmware (self-test mode off): listen-only CAN capture → timestamp → `.trc` write to microSD, button start/stop, LED status. | — |
| 2 | Capture a live 500 kbit/s bus for ≥30 min; confirm zero dropped frames and file integrity (`python-can` TRCReader / `tools/trc_viz.html`). | — |
| 3 | Power-source hot-swap USB↔12 V mid-capture; confirm the board survives the diode-OR handoff (data loss on cut is acceptable — out of scope). | — |
| 4 | Thermal soak at 12 V for ≥1 hr; log rail voltages and U1/U2/U4 temps. | — |
| 5 | EN-reset and power-cycle stress (×20): confirm deterministic boot every time. | — |

---

## 10. Sign-off checklist

- [ ] No rail shorts; +5VD and +3V3 in spec on both USB and 12 V
- [x] Native USB enumerates; flash 4 MB / no PSRAM confirmed (matches `-N4`); repeatable boot
- [ ] Strapping clean; **IO35 silent-pin rework confirmed** (IO45 unstuffed/floating)
- [ ] CAN RX in listen-only verified; no bus ACK/TX; normal-mode TX works on isolated bus
- [ ] microSD 4-bit mount + sustained write, CRC-clean
- [ ] Button + external/onboard LEDs functional
- [ ] Reverse-polarity and diode-OR protection verified
- [ ] ≥30 min live capture, zero drops; thermal soak passed
- [x] `esp32s3` firmware port complete (pin map, three-LED status, no PSRAM, 4 MB, native-USB console) — builds clean; hardware verification is the unchecked boxes above
- [ ] Self-test mode merged and Kconfig-gated off for production builds — **not built**; see the firmware-approach note at the top

---

*Pin map derived from the committed KiCad schematic netlist. Re-verify against the
schematic if the board is respun.*

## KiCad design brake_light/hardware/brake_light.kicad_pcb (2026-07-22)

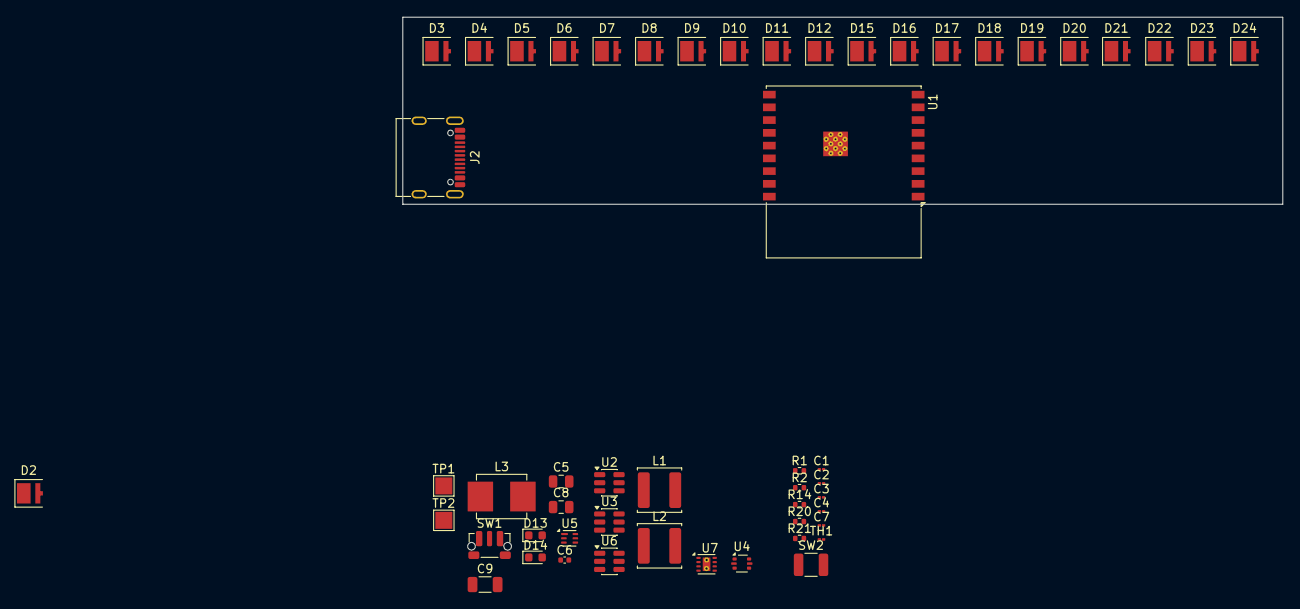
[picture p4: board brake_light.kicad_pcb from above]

Board: 4 copper layers, 103.5 x 22.0 mm, 53 parts (0 on the bottom side), 45 nets, no tracks yet.

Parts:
C1, C2, C3: 1u; C_01005_0402Metric
C4, C7: 0.22u; C_01005_0402Metric
C5, C8: 10u; C_0805_2012Metric
C6: 100n; C_0402_1005Metric
C9: 22u; C_1206_3216Metric
D2, D3, D4, D5, D6, D7, D8, D9, D10, D11, D12, D15, D16, D17, D18, D19, D20, D21, D22, D23, D24: LED; LED_Luminus_MP-3030-1100_3.0x3.0mm
D13: RED; LED_0603_1608Metric
D14: GRN; LED_0603_1608Metric
J2: USB_C_Receptacle_USB2.0_14P; USB_C_Receptacle_G-Switch_GT-USB-7010ASV
L1, L2: 22u 1.1A; L_Sunlord_SWPA5020S
L3: 2.2u; L_Murata_LQH55DN_5.7x5.0mm
R1, R2: 5.1K; R_0402_1005Metric
R14: 1K; R_0402_1005Metric
R20, R21: 100; R_0402_1005Metric
SW1: BOOT/USER; SW_Push_1P1T-MP_NO_Horizontal_Alps_SKRTLAE010
SW2: RST; R_1210_3225Metric
TH1: Thermistor_NTC; R_01005_0402Metric
TP1: RX; TestPoint_Pad_2.0x2.0mm
TP2: TX; TestPoint_Pad_2.0x2.0mm
U1: ESP32-C3-WROOM-02
U2: BQ21040DBV; SOT-23-6
U3, U6: AP3019AKTR; SOT-23-6
U4: USBLC6-2P6; SOT-666
U5: ISL29035; Renesas_DFN-6_1.5x1.6mm_P0.5mm
U7: TPS62162DSGR; WSON-8-1EP_2x2mm_P0.5mm_EP0.9x1.6mm_ThermalVias

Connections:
+3.3V: C1.1, C5.1, C6.1, C9.1, L3.2, U1.1 (3V3), U5.1 (VDD), U7.6 (VOS)
+5VD: J2.A4 (VBUS), J2.A9 (VBUS), J2.B4 (VBUS), J2.B9 (VBUS), U2.6 (VIN), U4.5 (VBUS)
/DN: J2.A7 (D-), J2.B7 (D-), U1.13 (IO18), U4.1 (I/O1), U4.6 (I/O1)
/DP: J2.A6 (D+), J2.B6 (D+), U1.14 (IO19), U4.3 (I/O2), U4.4 (I/O2)
/EN: R14.1, SW2.1, U1.2 (EN)
/VBAT: C2.1, C3.1, C8.1, L1.2, L2.2, U2.2 (OUT), U3.6 (V_{IN}), U6.6 (V_{IN}), U7.2 (VIN), U7.3 (EN)
GND: C1.2, C2.2, C3.2, C4.2, C5.2, C6.2, C7.2, C8.2, C9.2, D13.1 (K), D14.1 (K), J2.A1 (GND), J2.A12 (GND), J2.B1 (GND), J2.B12 (GND), J2.SH (SHIELD), R1.2, R2.2, SW1.2, SW2.2, TH1.1, U1.9 (GND), U1.19 (GND), U2.5 (GND), U3.2 (GND), U4.2 (GND), U5.2 (GND), U6.2 (GND), U7.1 (PGND), U7.4 (AGND), U7.5 (FB), U7.9 (PAD)
unnamed: D2.1 (K), U2.3 (~CHG)
unnamed: C4.1, D3.2 (A), U3.5 (V_{OUT})
unnamed: D3.1 (K), D4.2 (A)
unnamed: D4.1 (K), D5.2 (A)
unnamed: D5.1 (K), D6.2 (A)
unnamed: D6.1 (K), D7.2 (A)
unnamed: D7.1 (K), D8.2 (A)
unnamed: D8.1 (K), D9.2 (A)
unnamed: D9.1 (K), D10.2 (A)
unnamed: D10.1 (K), D11.2 (A)
unnamed: D11.1 (K), D12.2 (A)
unnamed: D12.1 (K), U3.3 (FB)
unnamed: D13.2 (A), R21.2
unnamed: D14.2 (A), R20.2
unnamed: C7.1, D15.2 (A), U6.5 (V_{OUT})
unnamed: D15.1 (K), D16.2 (A)
unnamed: D16.1 (K), D17.2 (A)
unnamed: D17.1 (K), D18.2 (A)
unnamed: D18.1 (K), D19.2 (A)
unnamed: D19.1 (K), D20.2 (A)
unnamed: D20.1 (K), D21.2 (A)
unnamed: D21.1 (K), D22.2 (A)
unnamed: D22.1 (K), D23.2 (A)
unnamed: D23.1 (K), D24.2 (A)
unnamed: D24.1 (K), U6.3 (FB)
unnamed: J2.A5 (CC1), R1.1
unnamed: J2.B5 (CC2), R2.1
unnamed: U1.18 (IO0), U5.6 (SDA)
unnamed: U1.17 (IO1), U5.5 (SCL)
unnamed: U1.15 (IO3), U5.4 (~INT)
unnamed: SW1.1, U1.8 (IO9)
unnamed: TP2.1 (1_1), U1.11 (IO20/RXD)
unnamed: TP1.1 (1_1), U1.12 (IO21/TXD)
unnamed: TH1.2, U2.1 (TS)
unnamed: L1.1, U3.1 (SW)
unnamed: L2.1, U6.1 (SW)
unnamed: R14.2, U7.8 (PG)
unnamed: L3.1, U7.7 (SW)

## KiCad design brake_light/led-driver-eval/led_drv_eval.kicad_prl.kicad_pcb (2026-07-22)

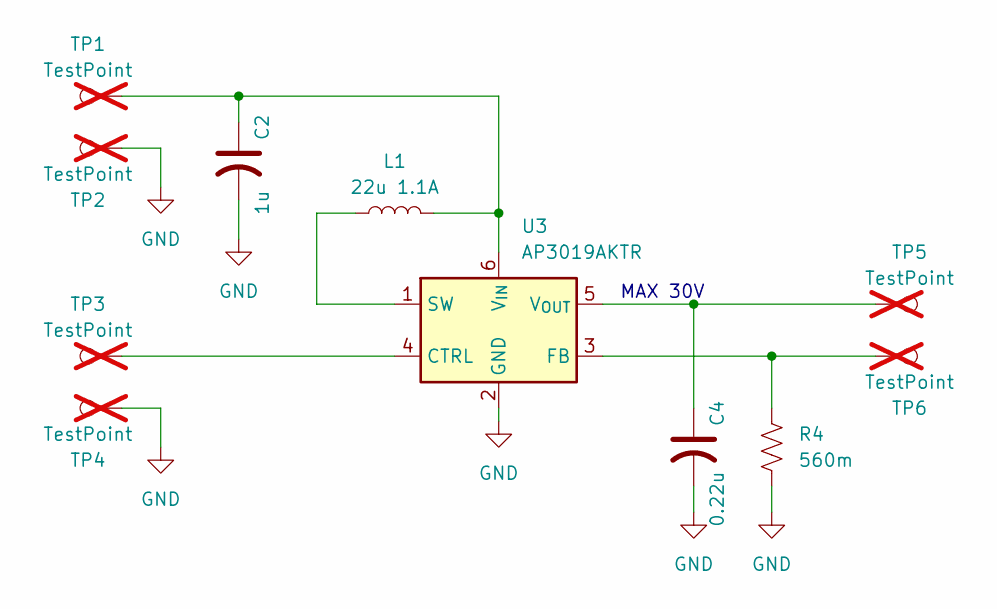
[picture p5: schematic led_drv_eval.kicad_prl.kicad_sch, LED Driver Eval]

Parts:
C2: 1u; C_0603_1608Metric; LCSC LMK107B7105KA-T
C4: 0.22u; C_0603_1608Metric; LCSC C107083
L1: 22u 1.1A; L_Sunlord_SWPA5020S; LCSC C96915
R4: 560m; R_1206_3216Metric; LCSC C5844413
TP1, TP2, TP3, TP4, TP5, TP6: TestPoint; TestPoint_Plated_Hole_D2.0mm; LCSC DNI; not fitted
U3: AP3019AKTR; SOT-23-6; LCSC C44956

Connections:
GND: C2.2, C4.2, R4.1, TP2.1 (1_1), TP4.1 (1_1), U3.2 (GND)
unnamed: TP3.1 (1_1), U3.4 (CTRL)
unnamed: R4.2, TP6.1 (1_1), U3.3 (FB)
unnamed: L1.1, U3.1 (SW)
unnamed: C2.1, L1.2, TP1.1 (1_1), U3.6 (V_{IN})
unnamed: C4.1, TP5.1 (1_1), U3.5 (V_{OUT})

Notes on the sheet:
MAX 30V

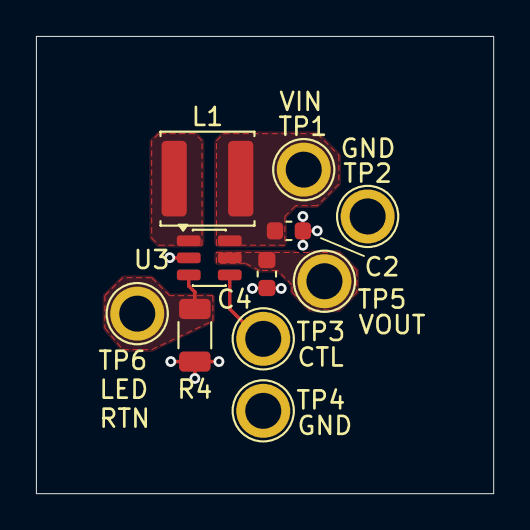
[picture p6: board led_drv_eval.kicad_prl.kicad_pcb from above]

Board: 2 copper layers, 25.4 x 25.4 mm, 11 parts (0 on the bottom side), 6 nets.

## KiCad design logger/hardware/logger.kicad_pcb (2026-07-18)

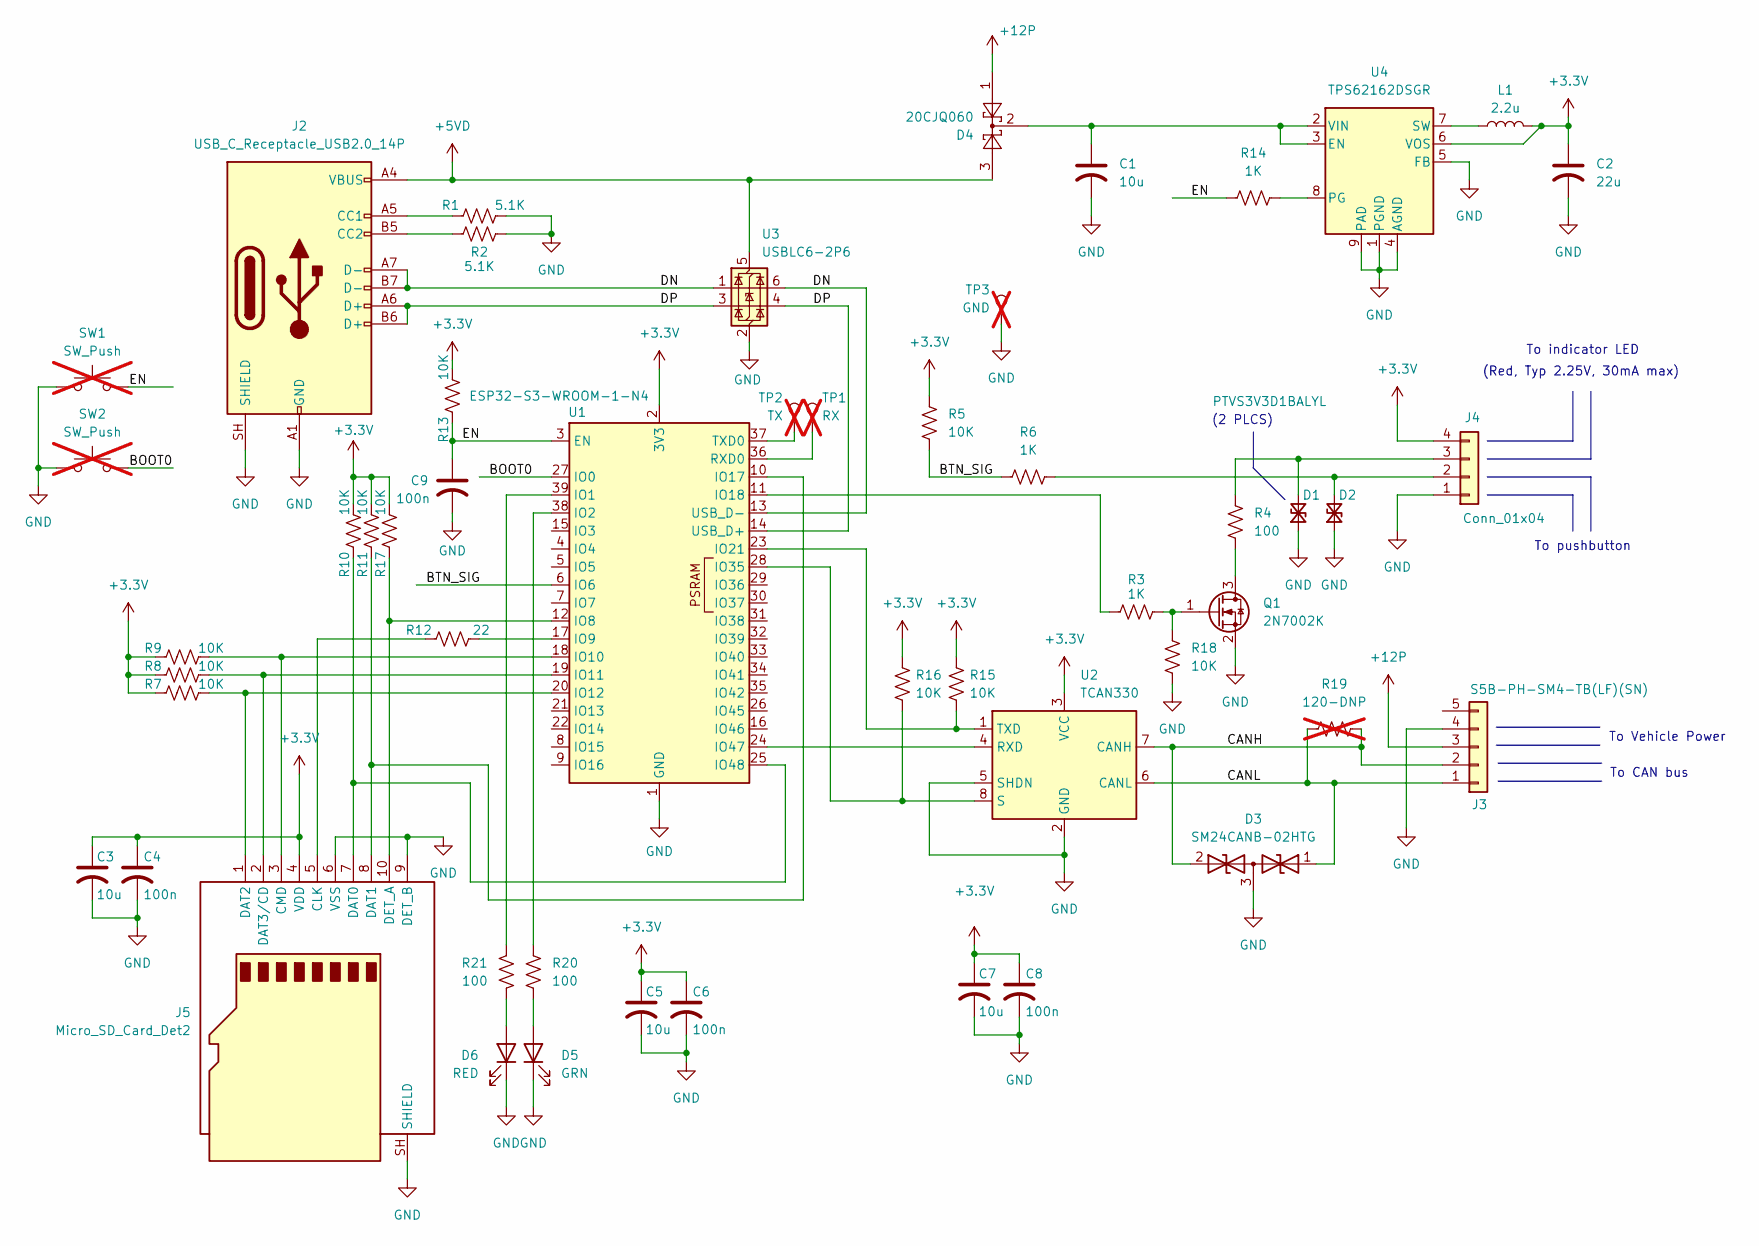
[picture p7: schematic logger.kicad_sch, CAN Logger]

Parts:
C1, C3, C5, C7: 10u; C_0805_2012Metric; LCSC C5677680
C2: 22u; C_1206_3216Metric; LCSC C91604
C4, C6, C8, C9: 100n; C_0402_1005Metric; LCSC C1525
D1, D2: PTVS3V3D1BALYL; D_SOD-882; LCSC C553419
D3: SM24CANB-02HTG; SOT-23; LCSC C151237
D4: 20CJQ060; SOT-223-3_TabPin2; LCSC C260229
D5: GRN; LED_0603_1608Metric; LCSC C125094
D6: RED; LED_0603_1608Metric; LCSC C94869
J2: USB_C_Receptacle_USB2.0_14P; USB_C_Receptacle_G-Switch_GT-USB-7010ASV; LCSC C2988369
J3: S5B-PH-SM4-TB(LF)(SN); JST_PH_S5B-PH-SM4-TB_1x05-1MP_P2.00mm_Horizontal; LCSC C265104
J4: Conn_01x04; JST_PH_S4B-PH-SM4-TB_1x04-1MP_P2.00mm_Horizontal; LCSC C265102
J5: Micro_SD_Card_Det2; microSD_HC_Molex_104031-0811; LCSC C585350
L1: 2.2u; L_Murata_LQH55DN_5.7x5.0mm; LCSC C701284
Q1: 2N7002K; SOT-23; LCSC C81445
R1, R2: 5.1K; R_0402_1005Metric; LCSC C105872
R3, R6, R14: 1K; R_0402_1005Metric; LCSC C106235
R4, R20, R21: 100; R_0402_1005Metric; LCSC C25076
R5, R7, R8, R9, R10, R11, R13, R15, R16, R17, R18: 10K; R_0402_1005Metric; LCSC C60490
R12: 22; R_0402_1005Metric; LCSC C114765
R19: 120-DNP; R_0402_1005Metric; LCSC DNI; not fitted
SW1, SW2: SW_Push; R_1210_3225Metric; LCSC DNI; not fitted
TP1: RX; TestPoint_Pad_2.0x2.0mm; LCSC DNI; not fitted
TP2: TX; TestPoint_Pad_2.0x2.0mm; LCSC DNI; not fitted
TP3: GND; TestPoint_Pad_2.0x2.0mm; LCSC DNI; not fitted
U1: ESP32-S3-WROOM-1-N4; ESP32-S3-WROOM-1; LCSC C2913197
U2: TCAN330; SOIC-8_3.9x4.9mm_P1.27mm; LCSC C2652876
U3: USBLC6-2P6; SOT-666; LCSC C15999
U4: TPS62162DSGR; WSON-8-1EP_2x2mm_P0.5mm_EP0.9x1.6mm_ThermalVias; LCSC C40256

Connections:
+3.3V: C2.1, C3.1, C4.1, C5.1, C6.1, C7.1, C8.1, J4.4, J5.4 (VDD), L1.2, R5.1, R7.1, R8.1, R9.1, R10.2, R11.2, R13.2, R15.1, R16.1, R17.2, U1.2 (3V3), U2.3 (VCC), U4.6 (VOS)
+5VD: D4.3, J2.A4 (VBUS), J2.A9 (VBUS), J2.B4 (VBUS), J2.B9 (VBUS), U3.5 (VBUS)
+12P: D4.1, J3.3
/BOOT0: SW2.2, U1.27 (IO0)
/BTN_SIG: R5.2, R6.1, U1.6 (IO6)
/CANH: D3.2 (A2), J3.2, R19.2, U2.7 (CANH)
/CANL: D3.1 (A1), J3.1, R19.1, U2.6 (CANL)
/DN: J2.A7 (D-), J2.B7 (D-), U1.13 (USB_D-), U3.1 (I/O1), U3.6 (I/O1)
/DP: J2.A6 (D+), J2.B6 (D+), U1.14 (USB_D+), U3.3 (I/O2), U3.4 (I/O2)
/EN: C9.1, R13.1, R14.1, SW1.2, U1.3 (EN)
GND: C1.2, C2.2, C3.2, C4.2, C5.2, C6.2, C7.2, C8.2, C9.2, D1.1 (A1), D2.1 (A1), D3.3 (common), D5.1 (K), D6.1 (K), J2.A1 (GND), J2.A12 (GND), J2.B1 (GND), J2.B12 (GND), J2.SH (SHIELD), J3.4, J4.1, J5.6 (VSS), J5.9 (DET_B), J5.SH (SHIELD), Q1.2 (S), R1.2, R2.2, R18.2, SW1.1, SW2.1, TP3.1 (1_1), U1.1 (GND), U1.40 (GND), U1.41 (GND), U2.2 (GND), U2.5 (SHDN), U3.2 (GND), U4.1 (PGND), U4.4 (AGND), U4.5 (FB), U4.9 (PAD)
unnamed: D1.2 (A2), J4.3, R4.1
unnamed: D2.2 (A2), J4.2, R6.2
unnamed: D5.2 (A), R20.2
unnamed: D6.2 (A), R21.2
unnamed: J2.A5 (CC1), R1.1
unnamed: J2.B5 (CC2), R2.1
unnamed: J5.5 (CLK), R12.1
unnamed: J5.3 (CMD), R9.2, U1.18 (IO10)
unnamed: J5.7 (DAT0), R10.1, U1.25 (IO48)
unnamed: J5.8 (DAT1), R11.1, U1.10 (IO17)
unnamed: J5.1 (DAT2), R7.2, U1.20 (IO12)
unnamed: J5.2 (DAT3/CD), R8.2, U1.19 (IO11)
unnamed: J5.10 (DET_A), R17.1, U1.12 (IO8)
unnamed: Q1.3 (D), R4.2
unnamed: Q1.1 (G), R3.2, R18.1
unnamed: R21.1, U1.39 (IO1)
unnamed: R20.1, U1.38 (IO2)
unnamed: R12.2, U1.17 (IO9)
unnamed: R3.1, U1.11 (IO18)
unnamed: R15.2, U1.23 (IO21), U2.1 (TXD)
unnamed: R16.2, U1.28 (IO35), U2.8 (S)
unnamed: U1.24 (IO47), U2.4 (RXD)
unnamed: TP1.1 (1_1), U1.36 (RXD0)
unnamed: TP2.1 (1_1), U1.37 (TXD0)
unnamed: C1.1, D4.2, U4.2 (VIN), U4.3 (EN)
unnamed: R14.2, U4.8 (PG)
unnamed: L1.1, U4.7 (SW)

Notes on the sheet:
To indicator LED
To Vehicle Power
To CAN bus
(2 PLCS)
(Red, Typ 2.25V, 30mA max)
To pushbutton

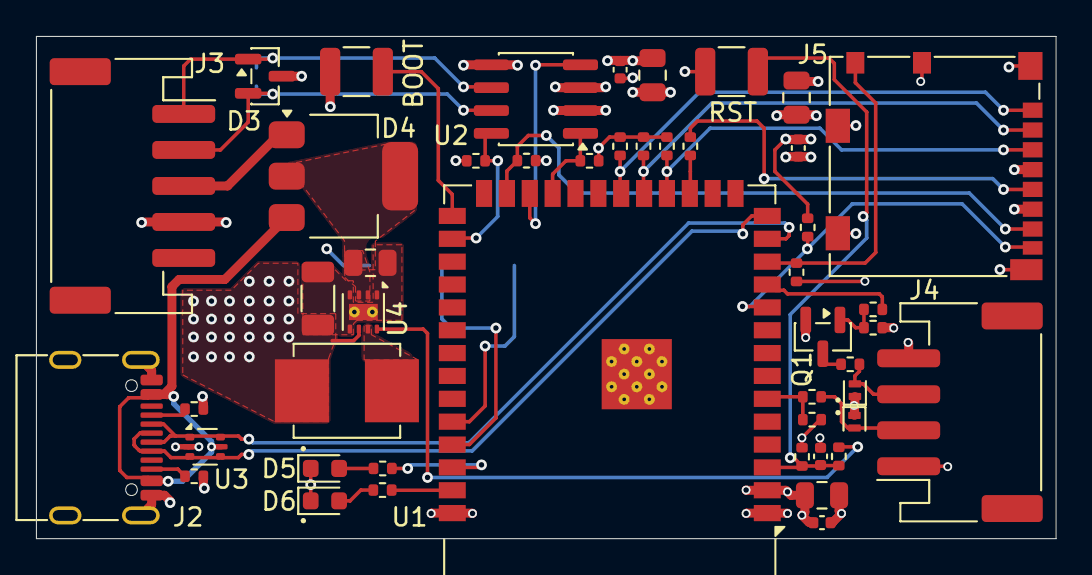
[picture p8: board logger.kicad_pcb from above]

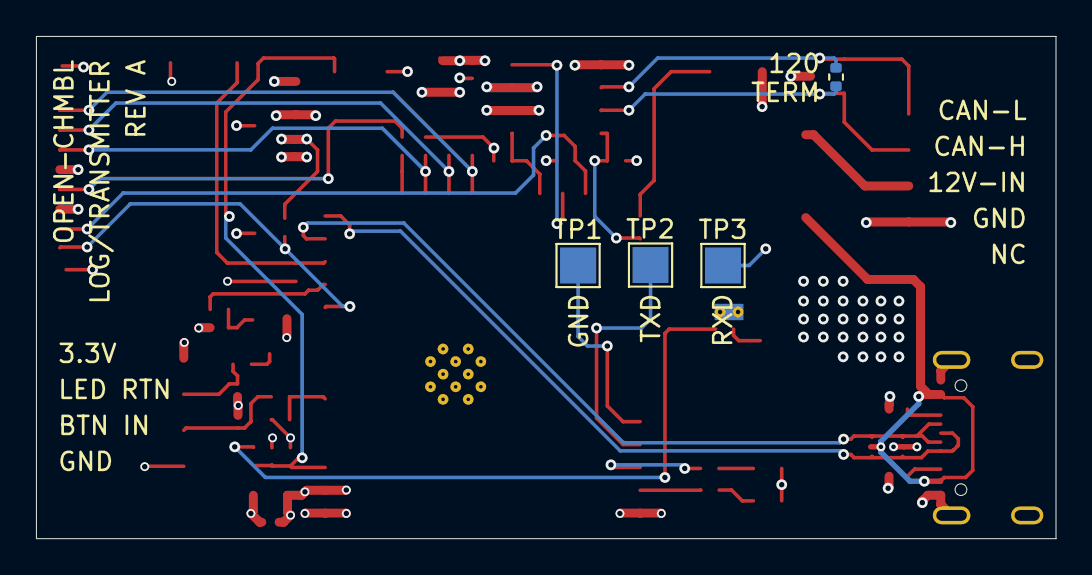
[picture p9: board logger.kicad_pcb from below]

Board: 4 copper layers, 56.6 x 27.9 mm, 51 parts (4 on the bottom side), 38 nets.

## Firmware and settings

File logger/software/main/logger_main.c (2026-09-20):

/*
 * open-chmbl CAN data logger — firmware for the custom logger PCB
 * (ESP32-S3-WROOM-1-N4; logger/hardware/logger.kicad_sch).
 *
 * Captures ALL CAN traffic (no filtering) in listen-only mode and writes it to
 * the microSD as PCAN .trc (v2.1) ASCII files. A single debounced pushbutton
 * (IO6, on the operator's pod at J4) toggles recording: each start opens a new
 * N.trc (N an increasing integer), each stop closes it. Three LEDs show logger
 * state, bus liveness and card activity at a glance (status_led.h); the full
 * operations log goes to the console over native USB.
 *
 * This is the DE-07 "ride logger" — a self-contained replacement for the
 * Raspberry Pi rig (see docs/can-profiles.md §3). Power-loss robustness is
 * intentionally out of scope; card removal is handled only to the extent of
 * shutting the capture down cleanly rather than wedging the writer.
 *
 * SILENT MODE IS A HARDWARE PROPERTY HERE. R16 pulls the TCAN330's S pin
 * (IO35 — U1 pin 28) up to 3V3, and the firmware never drives that pin: it is
 * configured high-impedance and left there. The transceiver is therefore silent
 * from power-on, before app_main runs, and stays silent through a crash. The
 * TWAI controller is *also* held in listen-only mode. Both halves of the
 * project's golden rule — never disturb a live vehicle bus — are in force.
 *
 * Tasks:
 *   CAN-RX   — twai_receive(); flags bus liveness for D5, and while recording
 *              timestamps each frame and queues it; counts drops if full.
 *   Writer   — owns the microSD, the open file and the recording state. Serves
 *              the control queue first (so button toggles and card events act
 *              promptly), then drains the frame queue.
 *   Card-det — polls DET_A (IO8) and posts insert/remove to the control queue.
 */

#include <dirent.h>
#include <stdio.h>
#include <stdlib.h>
#include <string.h>
#include <sys/stat.h>

#include "driver/gpio.h"
#include "driver/sdmmc_host.h"
#include "driver/twai.h"
#include "esp_err.h"
#include "esp_log.h"
#include "esp_timer.h"
#include "esp_vfs_fat.h"
#include "freertos/FreeRTOS.h"
#include "freertos/queue.h"
#include "freertos/task.h"
#include "sdmmc_cmd.h"
#include "sdkconfig.h"

#include "button_gpio.h"
#include "iot_button.h"

#include "status_led.h"
#include "trc_format.h"
#include "ui_log.h"

#define TRC_DIR         "/sdcard"
#define RX_QUEUE_LEN    CONFIG_LOGGER_RX_QUEUE_LEN
#define CTRL_QUEUE_LEN  8

/* Full-buffering size for the .trc stream. The default newlib buffer (~128 B)
 * flushes an SD block write every few frames; at motorcycle bus loads (~1500
 * frames/s here) those tiny writes cap the writer near ~400 frames/s and the
 * RX-to-writer queue overflows. A large buffer batches writes into full SD
 * clusters, lifting the ceiling far above the offered load. */
#define TRC_IO_BUF_SIZE (32 * 1024)

/* DET_A polling. 50 ms sampling with a 3-sample agreement filter debounces the
 * mechanical detect switch in ~150 ms — far below human insert/remove speed,
 * and slow enough that a bouncing contact can't spam the control queue. */
#define CARD_POLL_MS      50
#define CARD_STABLE_POLLS 3

/* A CAN frame stamped with its receive time (esp_timer microseconds). */
typedef struct {
    int64_t     t_us;
    trc_frame_t frame;
} ts_frame_t;

typedef enum {
    CMD_TOGGLE,
    CMD_CARD_INSERTED,
    CMD_CARD_REMOVED,
} logger_cmd_t;

static QueueHandle_t    s_frame_q;
static QueueHandle_t    s_ctrl_q;

static volatile bool     s_recording;   /* read by CAN-RX, written by Writer */
static volatile uint32_t s_dropped;     /* frames dropped on a full queue     */
static bool              s_sd_ok;        /* microSD mounted successfully       */
static unsigned          s_next_num = 1; /* next N.trc file number             */

/* ---- CAN bit-rate selection (Kconfig) ------------------------------------ */

static twai_timing_config_t logger_timing(void)
{
#if defined(CONFIG_LOGGER_CAN_BITRATE_125K)
    return (twai_timing_config_t)TWAI_TIMING_CONFIG_125KBITS();
#elif defined(CONFIG_LOGGER_CAN_BITRATE_250K)
    return (twai_timing_config_t)TWAI_TIMING_CONFIG_250KBITS();
#elif defined(CONFIG_LOGGER_CAN_BITRATE_1M)
    return (twai_timing_config_t)TWAI_TIMING_CONFIG_1MBITS();
#else
    return (twai_timing_config_t)TWAI_TIMING_CONFIG_500KBITS();
#endif
}

static const char *logger_bitrate_str(void)
{
#if defined(CONFIG_LOGGER_CAN_BITRATE_125K)
    return "125k";
#elif defined(CONFIG_LOGGER_CAN_BITRATE_250K)
    return "250k";
#elif defined(CONFIG_LOGGER_CAN_BITRATE_1M)
    return "1M";
#else
    return "500k";
#endif
}

static const char *logger_mode_str(void)
{
#if CONFIG_LOGGER_CAN_LISTEN_ONLY
    return "listen-only";
#else
    return "normal/ACK";
#endif
}

/* ---- Indicator state ------------------------------------------------------ */

/* Latched once the CAN silent pin reads low. That is the one fault the operator
 * must not be able to lose track of — everything else here is recoverable, but a
 * transceiver that might not be silent stays reported until the board is power
 * cycled. Without the latch a successful microSD mount a few lines later in
 * app_main would quietly reset the indicator to idle. */
static bool s_silent_fault;

/* Set the indicator state, honouring the latch. Use this rather than calling
 * status_led_set() directly from anywhere in this file. */
static void logger_set_state(led_state_t state)
{
    status_led_set(s_silent_fault ? LED_STATE_ERROR : state);
}

/* ---- CAN transceiver silent pin ------------------------------------------ */

/* Park the TCAN330's S pin (IO35) high-impedance so R16's pull-up to 3V3 holds
 * the transceiver in silent mode. We never drive this pin — see the file header.
 *
 * Both internal pulls are disabled on purpose: an internal pull-up would hold S
 * high even if R16 were missing or unstuffed, hiding exactly the board fault
 * that would let us transmit onto a live bus. Same reasoning as DET_A in
 * BRINGUP.md §4.5, but the stakes are higher here. */
static void can_silent_pin_init(void)
{
    const gpio_config_t cfg = {
        .pin_bit_mask = 1ULL << CONFIG_LOGGER_CAN_SILENT_GPIO,
        .mode = GPIO_MODE_INPUT,
        .pull_up_en = GPIO_PULLUP_DISABLE,
        .pull_down_en = GPIO_PULLDOWN_DISABLE,
        .intr_type = GPIO_INTR_DISABLE,
    };
    ESP_ERROR_CHECK(gpio_config(&cfg));

    /* Read it back: high means R16 is doing its job. A low reading means the
     * transceiver is NOT silent and could ACK a live bus — say so loudly. */
    const int level = gpio_get_level(CONFIG_LOGGER_CAN_SILENT_GPIO);
    ui_log_line("CAN silent pin IO%d = %d (hi-z, R16 pull-up)",
                CONFIG_LOGGER_CAN_SILENT_GPIO, level);
    if (level != 1) {
        ui_log_line("WARNING: silent pin reads LOW — transceiver may not be silent!");
        ui_log_line("  check R16; do NOT connect to a vehicle bus until resolved");
        s_silent_fault = true;
        logger_set_state(LED_STATE_ERROR);
    }
}

/* ---- microSD -------------------------------------------------------------- */

static sdmmc_card_t *s_card;

/* DET_A is active-low: R17 pulls it up, a seated card pulls J5 pin10 to GND. */
static bool sd_card_present(void)
{
    return gpio_get_level(CONFIG_LOGGER_SD_DET_GPIO) == 0;
}

static void sd_det_init(void)
{
    const gpio_config_t cfg = {
        .pin_bit_mask = 1ULL << CONFIG_LOGGER_SD_DET_GPIO,
        .mode = GPIO_MODE_INPUT,
        .pull_up_en = GPIO_PULLUP_DISABLE,   /* R17 does this — see Kconfig */
        .pull_down_en = GPIO_PULLDOWN_DISABLE,
        .intr_type = GPIO_INTR_DISABLE,
    };
    ESP_ERROR_CHECK(gpio_config(&cfg));
}

/* Mount the microSD as FAT at TRC_DIR over the S3's SDMMC host, on the pins the
 * logger PCB routes (BRINGUP.md §0). Returns true on success.
 *
 * Card-detect is NOT handed to the driver (slot.cd stays NC) even though it
 * supports it: we gate on DET_A ourselves so a missing card produces our own
 * log line and LED state rather than an opaque mount error. */
static bool sd_mount(void)
{
    const esp_vfs_fat_sdmmc_mount_config_t mount_cfg = {
        .format_if_mount_failed = false,
        .max_files = 5,
        .allocation_unit_size = 16 * 1024,
    };

    sdmmc_host_t host = SDMMC_HOST_DEFAULT();               /* SDMMC slot 1 */
    sdmmc_slot_config_t slot = SDMMC_SLOT_CONFIG_DEFAULT();

    /* The S3 routes SDMMC through the GPIO matrix, so the pins are explicit
     * rather than fixed IO-MUX assignments as they were on the ESP32. */
    slot.clk = CONFIG_LOGGER_SD_CLK_GPIO;
    slot.cmd = CONFIG_LOGGER_SD_CMD_GPIO;
    slot.d0  = CONFIG_LOGGER_SD_D0_GPIO;
#if CONFIG_LOGGER_SD_BUS_WIDTH_4
    slot.d1  = CONFIG_LOGGER_SD_D1_GPIO;
    slot.d2  = CONFIG_LOGGER_SD_D2_GPIO;
    slot.d3  = CONFIG_LOGGER_SD_D3_GPIO;
    slot.width = 4;
#else
    slot.width = 1;
#endif

    /* No SDMMC_SLOT_FLAG_INTERNAL_PULLUP: the board carries proper external
     * pull-ups (R7–R11), and the internal ones are documented as insufficient
     * anyway. Enabling them would only mask an unstuffed resistor. */

    esp_err_t err = esp_vfs_fat_sdmmc_mount(TRC_DIR, &host, &slot, &mount_cfg, &s_card);
    if (err != ESP_OK) {
        ui_log_line("mount failed: %s", esp_err_to_name(err));
        return false;
    }
    return true;
}

static void sd_unmount(void)
{
    esp_vfs_fat_sdcard_unmount(TRC_DIR, s_card);
    s_card = NULL;
}

/* ---- microSD file bookkeeping -------------------------------------------- */

/* One pass over the card root: log every file found (the boot-time inventory
 * the operator sees on the console), and set s_next_num = max(N in N.trc) + 1
 * so a new capture never overwrites an old one. */
static void sd_scan_and_list(void)
{
    DIR *dir = opendir(TRC_DIR);
    if (dir == NULL) {
        ui_log_line("cannot list %s (opendir failed)", TRC_DIR);
        s_next_num = 1;
        return;
    }

    unsigned max_n = 0;
    int total = 0;
    int trc = 0;

    ui_log_line("card contents:");
    struct dirent *ent;
    while ((ent = readdir(dir)) != NULL) {
        total++;

        char path[280];
        snprintf(path, sizeof(path), "%s/%s", TRC_DIR, ent->d_name);
        struct stat st;
        if (stat(path, &st) == 0) {
            ui_log_line("  %-14s %lu bytes", ent->d_name, (unsigned long)st.st_size);
        } else {
            ui_log_line("  %-14s (size unavailable)", ent->d_name);
        }

        /* Match "<digits>.trc" exactly (nothing trailing). */
        unsigned n = 0;
        int consumed = 0;
        if (sscanf(ent->d_name, "%u.trc%n", &n, &consumed) == 1 &&
            consumed == (int)strlen(ent->d_name)) {
            trc++;
            if (n > max_n) {
                max_n = n;
            }
        }
    }
    closedir(dir);

    if (total == 0) {
        ui_log_line("  (empty)");
    }
    s_next_num = max_n + 1;
    ui_log_line("%d file(s), %d .trc capture(s), highest #%u", total, trc, max_n);
    ui_log_line("next file number = %u", s_next_num);
}

/* Mount and inventory the card, reporting each step. Shared by the boot path
 * and the runtime card-insert path so both log identically. */
static void sd_bring_up(void)
{
    if (!sd_card_present()) {
        ui_log_line("microSD: NO CARD DETECTED (DET_A/IO%d high)",
                    CONFIG_LOGGER_SD_DET_GPIO);
        s_sd_ok = false;
        logger_set_state(LED_STATE_ERROR);
        return;
    }

    ui_log_line("microSD: card detected (DET_A/IO%d low)", CONFIG_LOGGER_SD_DET_GPIO);

    s_sd_ok = sd_mount();
    if (!s_sd_ok) {
        ui_log_line("microSD: filesystem mount FAILED");
        logger_set_state(LED_STATE_ERROR);
        return;
    }

    ui_log_line("microSD: filesystem mounted at %s", TRC_DIR);
    if (s_card != NULL) {
        /* The width actually negotiated, not the width the card is capable of:
         * log_bus_width is log2(capability), so reporting it directly would
         * claim "2-bit" for a healthy 4-bit link and, worse, would look
         * identical whether or not the DAT1-3 lines came up. BRINGUP.md §6.2/§6.3
         * turn on telling those two apart. This mirrors sdmmc_card_print_info(). */
        const int bus_width = s_card->is_mmc ? (1 << s_card->log_bus_width)
                                             : (s_card->ssr.cur_bus_width ? 4 : 1);
        ui_log_line("  %s, %llu MB, %d-bit bus", s_card->cid.name,
                    ((uint64_t)s_card->csd.capacity * s_card->csd.sector_size) / (1024 * 1024),
                    bus_width);
    }
    sd_scan_and_list();
    logger_set_state(LED_STATE_IDLE);
}

/* ---- Writer task: owns the file + recording state ------------------------ */

static FILE   *s_file;
static char   *s_io_buf;      /* full-buffering block for s_file (see setvbuf) */
static uint32_t s_msgnr;
static int64_t  s_t0_us;      /* timestamp of the first frame in this file */
static uint32_t s_file_frames;

/* Bytes buffered since the last flash of D6. The stream is fully buffered
 * (TRC_IO_BUF_SIZE), so frames do not each cause a card write — flashing per
 * frame would report the wrong thing and, at ~1500 frames/s, would peg D6 solid.
 * Counting up to a buffer's worth pulses the LED roughly when newlib actually
 * pushes a block to the card. */
static size_t s_bytes_buffered;

static void note_bytes_written(size_t n)
{
    s_bytes_buffered += n;
    if (s_bytes_buffered >= TRC_IO_BUF_SIZE) {
        s_bytes_buffered -= TRC_IO_BUF_SIZE;
        status_led_sd_activity();
    }
}

static void writer_start_recording(void)
{
    if (!sd_card_present()) {
        ui_log_line("cannot record: no microSD card");
        logger_set_state(LED_STATE_ERROR);
        return;
    }
    if (!s_sd_ok) {
        ui_log_line("cannot record: microSD not mounted");
        logger_set_state(LED_STATE_ERROR);
        return;
    }

    /* Discard any straggler frame the RX task may have queued right at the
     * previous stop, so it can't bleed into the new file. */
    ts_frame_t stale;
    while (xQueueReceive(s_frame_q, &stale, 0) == pdTRUE) {
    }

    char path[64];
    snprintf(path, sizeof(path), "%s/%u.trc", TRC_DIR, s_next_num);

    s_file = fopen(path, "w");
    if (s_file == NULL) {
        ui_log_line("open FAILED: %u.trc", s_next_num);
        logger_set_state(LED_STATE_ERROR);
        return;
    }

    /* Batch writes into full SD clusters (see TRC_IO_BUF_SIZE). Must be set
     * before any I/O on the stream, and the buffer must outlive it (freed in
     * writer_stop_recording). If the allocation fails, fall back to the default
     * small buffer rather than aborting the recording. */
    s_io_buf = malloc(TRC_IO_BUF_SIZE);
    if (s_io_buf != NULL) {
        setvbuf(s_file, s_io_buf, _IOFBF, TRC_IO_BUF_SIZE);
    } else {
        ui_log_line("warn: no I/O buffer, drops likely");
    }

    /* Reset the write accounting before the first byte goes out, so the header
     * counts toward the next activity flash like everything else. */
    s_bytes_buffered = 0;
    status_led_sd_activity();   /* the file create itself hits the card */

    char header[512];
    int hn = trc_format_header(header, sizeof(header));
    if (hn > 0) {
        fwrite(header, 1, (size_t)hn, s_file);
        note_bytes_written((size_t)hn);
    }

    ui_log_line("opened file %u.trc", s_next_num);
    s_msgnr = 0;
    s_file_frames = 0;
    s_t0_us = INT64_MIN;
    s_dropped = 0;

    s_recording = true;
    s_next_num++;
    ui_log_line("recording started");
    logger_set_state(LED_STATE_RECORDING);
}

/* Write one queued frame to the open file. */
static void writer_write_frame(const ts_frame_t *tf)
{
    if (s_file == NULL) {
        return;
    }
    if (s_t0_us == INT64_MIN) {
        s_t0_us = tf->t_us;
    }
    double time_ms = (double)(tf->t_us - s_t0_us) / 1000.0;

    char line[128];
    int n = trc_format_line(line, sizeof(line), ++s_msgnr, time_ms, &tf->frame);
    if (n > 0) {
        fwrite(line, 1, (size_t)n, s_file);
        fputc('\n', s_file);
        s_file_frames++;
        note_bytes_written((size_t)n + 1);
    }
}

static void writer_stop_recording(void)
{
    /* Stop accepting new frames, then flush what is already queued for this
     * file. The TWAI controller keeps running — it is what feeds the bus-liveness
     * indicator (D5) while idle. */
    s_recording = false;

    ts_frame_t tf;
    while (xQueueReceive(s_frame_q, &tf, 0) == pdTRUE) {
        writer_write_frame(&tf);
    }

    if (s_file != NULL) {
        /* Footer comment so every capture is self-documenting: readers skip
         * lines starting with ';', and "dropped-frames: N" is greppable. A
         * clean capture records 0, so absence of the line means an older/
         * truncated file, not a lossless one. */
        char footer[96];
        int fn = snprintf(footer, sizeof(footer),
                          ";dropped-frames: %u (RX-to-writer queue overflow)\n",
                          (unsigned)s_dropped);
        if (fn > 0) {
            fwrite(footer, 1, (size_t)fn, s_file);
        }
        fflush(s_file);
        fclose(s_file);
        s_file = NULL;
        free(s_io_buf);
        s_io_buf = NULL;
        status_led_sd_activity();   /* the final flush + close */
    }
    ui_log_line("recording stopped");
    logger_set_state(LED_STATE_IDLE);
    ui_log_line("file closed: %u frames%s", (unsigned)s_file_frames,
                s_dropped ? " (drops!)" : "");
    if (s_dropped) {
        ui_log_line("  dropped %u frames", (unsigned)s_dropped);
    }
}

/* Card yanked mid-capture. Nothing can be flushed — the file is whatever
 * reached the card before the contacts opened — so just release the handles
 * without pretending the tail was written. */
static void writer_abort_recording(void)
{
    s_recording = false;

    ts_frame_t tf;
    while (xQueueReceive(s_frame_q, &tf, 0) == pdTRUE) {
    }

    if (s_file != NULL) {
        fclose(s_file);
        s_file = NULL;
        free(s_io_buf);
        s_io_buf = NULL;
    }
    ui_log_line("recording ABORTED: card removed mid-capture");
    ui_log_line("  %u frames were written; the tail of the file is lost",
                (unsigned)s_file_frames);
}

static void writer_handle_toggle(void)
{
    if (s_recording) {
        writer_stop_recording();
    } else {
        writer_start_recording();
    }
}

static void writer_handle_card_inserted(void)
{
    ui_log_line("microSD: card inserted");
    if (s_sd_ok) {
        return;     /* already mounted; nothing to do */
    }
    sd_bring_up();
}

static void writer_handle_card_removed(void)
{
    ui_log_line("microSD: card removed");
    if (s_recording) {
        writer_abort_recording();
    }
    if (s_sd_ok) {
        sd_unmount();
        s_sd_ok = false;
        ui_log_line("microSD: unmounted");
    }
    logger_set_state(LED_STATE_ERROR);
}

static void writer_task(void *arg)
{
    (void)arg;
    for (;;) {
        /* Service control commands first so a toggle or a card event is always
         * acted on promptly, even while frames are flooding in. Then block
         * briefly on the frame queue: a silent-but-recording bus parks here
         * (letting lower-prio tasks run) while a control press is still noticed
         * within the timeout.
         *
         * NOTE: do not multiplex these two queues through a FreeRTOS queue set.
         * writer_start/stop_recording drain s_frame_q directly, and reading a
         * queue-set member outside xQueueSelectFromSet() desyncs the set's token
         * accounting -- which stranded/batched button toggles under heavy frame
         * load and left the status LED out of sync with the recording state. */
        logger_cmd_t cmd;
        if (xQueueReceive(s_ctrl_q, &cmd, 0) == pdTRUE) {
            switch (cmd) {
            case CMD_TOGGLE:         writer_handle_toggle();        break;
            case CMD_CARD_INSERTED:  writer_handle_card_inserted(); break;
            case CMD_CARD_REMOVED:   writer_handle_card_removed();  break;
            }
            continue;
        }

        ts_frame_t tf;
        if (xQueueReceive(s_frame_q, &tf, pdMS_TO_TICKS(20)) == pdTRUE) {
            writer_write_frame(&tf);
        }
    }
}

/* ---- CAN-RX task --------------------------------------------------------- */
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
void app_main(void)
{
    status_led_init();

    ui_log_line("booted — logger PCB (ESP32-S3)");
    ui_log_line("CAN %s %s", logger_bitrate_str(), logger_mode_str());

    /* Before anything else that could touch the bus. */
    can_silent_pin_init();

    sd_det_init();
    sd_bring_up();

    s_frame_q = xQueueCreate(RX_QUEUE_LEN, sizeof(ts_frame_t));
    s_ctrl_q  = xQueueCreate(CTRL_QUEUE_LEN, sizeof(logger_cmd_t));

    /* Install and start the controller BEFORE the RX task exists, so that task
     * never runs against a stopped controller. It defends against that anyway
     * (see can_rx_task), but not having the window is better than handling it. */
    can_init();

    xTaskCreate(writer_task, "trc_writer", 4096, NULL, 5, NULL);
    xTaskCreate(can_rx_task, "can_rx", 4096, NULL, 6, NULL);
    xTaskCreate(card_detect_task, "card_detect", 2560, NULL, 3, NULL);

    button_init();

    ui_log_line("ready: press to start/stop");
}

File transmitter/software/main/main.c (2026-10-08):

/*
 * transmitter (bike-side) firmware — entry point.
 *
 * Runs on the logger PCB (ESP32-S3-WROOM-1-N4, logger/hardware/), which is
 * also the transmitter's hardware: the same board with the microSD slot (J5)
 * and, in the final build, the remote pod connector (J4) unpopulated. See
 * docs/hardware.md §1. While J4 *is* populated on the bench board, its LED
 * output (IO18) stands in as the brake light.
 *
 * Bring-up order matters:
 *   status_led   first, so a fault found later has somewhere to show up;
 *   can_rx       parks the transceiver's silent pin before anything can
 *                touch the bus, then installs TWAI listen-only;
 *   brake_ctl    starts the 50 Hz DE-09 tick that drives the light;
 *   console      last, and only when CONFIG_CHMBL_CLI is set — everything
 *                above is real functionality and comes up regardless.
 */
#include "freertos/FreeRTOS.h"
#include "freertos/task.h"
#include "esp_log.h"
#include "sdkconfig.h"

#include "brake_ctl.h"
#include "can_rx.h"
#include "console.h"
#include "net.h"
#include "pairing.h"
#include "status_led.h"

static const char *TAG = "transmitter";

void app_main(void)
{
    ESP_LOGI(TAG, "transmitter starting — logger PCB (ESP32-S3)");

    status_led_init();
    pairing_init();
    net_init();
    can_rx_init();
    brake_ctl_init();

#if CONFIG_CHMBL_CLI
    console_start();
#else
    ESP_LOGW(TAG, "developer CLI disabled (CONFIG_CHMBL_CLI=n)");
    while (1) {
        vTaskDelay(pdMS_TO_TICKS(1000));
    }
#endif
}

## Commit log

2026-06-24 Add Open-CHMBL system architecture and repo skeleton
    Document the design for a CAN-bus-driven, ESP-NOW helmet brake light:
    - ARCHITECTURE.md: system overview, reference-bike-first strategy,
    braking state machine, wireless link, safety constraints
    - docs/: hardware, firmware, protocol, can-profiles, safety-regulatory, roadmap
    - transmitter/ and brake_light/ units, each with hardware/ and software/ subdirs
    Claude-Session: https://claude.ai/code/session_01E87DakYNsKwgXwh2Pmq9Qh
2026-06-24 Set Triumph Speed 400 as reference bike
    - Speed 400 + Scrambler 400 X share the TR-series single -> one CAN profile
    - Street Triple 765 as stretch target (separate platform, same 6-pin connector)
    - Document the red 6-pin OBD2 connector (CAN-H/L + K-line) under the seat
    - Flag the key risk: free-running broadcast vs. request/response on the diag port,
    which gates the listen-only approach
    - Update architecture, roadmap, and transmitter hardware notes accordingly
    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
2026-06-24 Document two-rig CAN reverse-engineering workflow
    - Rig A: PCAN-USB + PCAN-Explorer for stationary bench sniffing (and active
    request/response probing to settle the broadcast-mode question)
    - Rig B: Raspberry Pi / Pi Zero + SocketCAN ride-logger (listen-only) for
    in-motion signals, especially wheel speed
    - Add wheel_speed to the profile struct/decode table: gear inference + true road
    deceleration as DECEL calibration ground truth (CAN data, not an IMU)
    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
2026-06-24 Add feature-function lists, design-element framework, and developer CLI spec
    - docs/feature-functions.md: per-device capability decomposition with traceable
    FFL IDs (replaces shall-statement requirements)
    - docs/cli.md: per-device developer CLI to fake/view I/O, built on a
    source-override model that enables isolation testing of each element
    - docs/design/: process + design-doc template (component selection, I/O
    assignments, firmware module/task decomposition, CLI hooks) and an ordered
    build list; lean stubs for ESP-NOW link, auto-brightness, link-loss failsafe,
    CAN decode, and BRAKE/DECEL logic
    - Wire new docs into ARCHITECTURE, README, and roadmap (Phase 0/1)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
2026-06-25 docs: status-indicator LED, integrated C3 module survey, magnetic-mount exploration
    Brake-light governing-doc tweaks across three areas:
    - Status-indicator LED: new BL-IND feature area (color + blink-code fault
    reporting, independent of the main bar), DE-10 design element, firmware
    task + code table, CLI hooks (ind show/test/source), and hardware row.
    - ESP32-C3 module survey (hardware §2.1): candidates carrying an onboard
    WS2812 + LiPo charger to cut designed-in parts, with LCSC notes and a
    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
2026-06-25 docs: pacemaker/ICD warning and magnet force analysis for magnetic mount
    safety-regulatory.md §3:
    Add a dedicated implanted-cardiac-device bullet. Quantifies the 0.5 mT
    (5 gauss) interference threshold; shows the dipole-model geometry for
    garment vs. helmet mount; concludes that persons with pacemakers/ICDs
    must use only the helmet-mount configuration and consult their device
    manufacturer before riding with any magnet-based mount.
    explorations/mounting-magnetic.md:
    New "Force analysis and initial magnet sizing" section covering:
    - Hold-force floor: riding loads (aero ~5 N, inertial shock ~6 N,
    vibration ~2 N); 2.5× margin → hold ≥ 30 N target.
    - Release ceiling: cr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
2026-06-25 docs: clarify magnet dimensions as diameter × thickness (disc magnets)
    "20 mm × 4 mm" was ambiguous. All candidate specs, formula worked examples,
    and the safety-doc reference now explicitly read "dia. × thick" and label
    the magnet type as a disc.
    Claude-Session: https://claude.ai/code/session_01AiGHAwjCQ41fkCE6YEgaQR
2026-06-25 docs: switch magnet spec from H-grade to standard N-grade
    H-grade NdFeB is hard to source in small quantities. Standard N-grade
    (80°C continuous) is sufficient: the magnet lives inside the sealed
    enclosure rather than on the outer shell, riding airflow limits sustained
    temps, and the 70°C bench thermal-soak step gates the validation. Replace
    N42H/N35H/N48H with N42/N35/N48 throughout the candidate table, worked
    examples, and magnet-selection note.
    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
2026-06-26 Redesign braking logic around wheel-speed deceleration (no brake switch)
    The reference bike (Triumph Speed 400) does not publish a brake-switch bit
    on its CAN bus. Replace the brake-switch-authoritative state machine with one
    that infers braking entirely from CAN-available signals.
    State machine (OFF / BRAKING / STOPPED, both on-states render ST_BRAKE):
    - Turn ON when deceleration exceeds DECEL_ON_MPHPS (default 3 mph/s), or when
    speed drops below STOP_SPEED_MPH (default 1 mph) on the way to a stop.
    - Hold ON through a standstill.
    - Turn OFF on positive accel > ACCEL_OFF_MPHPS (0.5) above ACCEL_OFF_MIN_SPEED
    (5 mph), on steady speed (|accel| < STEADY_BAND for STEADY_TIMEOUT, 2 s),
    on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
2026-06-26 brake_light: bootstrap ESP-IDF firmware with bring-up blink + CI
    Add a minimal ESP-IDF v5.x project under brake_light/software that toggles a
    single GPIO LED, so we can prove the toolchain, board bring-up, and build
    before the real helmet-side firmware (ESP-NOW RX + LED pattern engine) lands.
    - Standard ESP-IDF layout: top-level CMakeLists, main component with blink.c.
    - Kconfig.projbuild exposes BLINK_GPIO (default GPIO8, ESP32-C3-DevKitM) and
    BLINK_PERIOD_MS.
    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
2026-06-26 transmitter: bootstrap ESP-IDF firmware with bring-up blink + add to CI
    Mirror the brake_light bootstrap on the bike side: a minimal ESP-IDF v5.x
    project under transmitter/software that toggles a single GPIO LED, proving the
    toolchain and build before the real firmware (TWAI/CAN + state machine +
    ESP-NOW TX) lands.
    - Standard ESP-IDF layout matching brake_light (CMakeLists, main/blink.c,
    Kconfig.projbuild with BLINK_GPIO default GPIO8 / BLINK_PERIOD_MS).
    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
2026-06-26 firmware: scope main's deps to esp_driver_gpio (drop implicit full-tree build)
    The `main` component, when it declares no REQUIRES/PRIV_REQUIRES, implicitly
    depends on every IDF component, so the build compiled the whole tree (wifi,
    lwip, esp_netif, mbedtls, bt, ...) even though a blink uses none of it. The
    unused code was stripped at link time, but it was wasted build time.
    Declare the only real dependency (GPIO driver) explicitly on both firmwares so
    IDF builds just that subgraph plus the common/boot components.
    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
2026-06-26 brake_light: add developer console (DE-00) over USB Serial/JTAG
    Start the developer CLI on brake_light using ESP-IDF's esp_console REPL,
    routed to the ESP32-C3 built-in USB Serial/JTAG controller — an enumerated
    virtual COM port over the native USB pins that also carries JTAG debugging on
    the same cable, so no external USB-TTL adapter is needed. UART is kept as a
    compile-time fallback.
    Replaces the bring-up blink with a console entry point and two commands:
    - `id` — chip unique ID (factory base MAC), model/revision, IDF version
    - `light [on|off|toggle]` — drive a stand-in brake-light GPIO until the real
    LED render engine (DE-04) lands
    Commands live in per-domain cmd_*.c fi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
    [cmd_light.c, console.c, main.c]
2026-06-27 docs(de-04): LED bar driver trade study — select TI LM3410 boost CC
    Add DE-04 (LED render & bar driver) with a full driver trade study driven
    to a conclusion, and wire it into the design index, hardware doc, and
    roadmap.
    Topology: single series string of >=3 high-power red (620-630nm) + boost
    constant-current driver. Series count is chosen so the string stays above
    the 1S battery (3.0-4.2V), making a plain boost valid across the whole
    discharge and avoiding a buck-boost.
    Driver decision: TI LM3410 (2.7-5.5V in, 2.8A/24V integrated switch,
    PWM+analog dim, OVP/thermal). The deciding gate is Vin-min: LM3410 reaches
    2.7V and uses the full 1S discharge, where TPS61500 (2.9V) and LT3518
    (3.0V)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
2026-06-27 docs: reconcile DE-04 driver study with the CHMSL brightness benchmark
    Incorporate the LED brightness/flux benchmark from the
    led-brightness-flux-benchmark branch and reconcile it with the DE-04
    driver trade study. The two were complementary but reached different
    emitter picks and left a gap between them; this resolves both.
    - Import docs/led-brightness-benchmark.md (CHMSL-anchored cd targets,
    candela->flux budget, addressable-RGB-rejected-by-flux-math).
    - DE-04 now defers photometry/emitter selection to the benchmark and
    adopts its down-select: discrete mid-power 2835/3030 red array
    (~8-12 emitters), replacing the earlier high-power x6 assumption. Correct
    the brightness target from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
2026-07-01 logger: fix -Werror=format build failure
    On xtensa (esp32) uint32_t is `long unsigned int`, so `%u` with
    s_file_frames tripped -Werror=format. Cast to unsigned in the ui_log_line
    call, and drop the unused TAG in logger_main.c (all logging goes through
    ui_log). Other format args were already plain unsigned or cast via
    (unsigned long) in trc_format.c.
    Claude-Session: https://claude.ai/code/session_01FxAHdgJgApJqP116jLAj5L
    [logger_main.c]
2026-07-01 logger: gate CAN controller to recording to fix idle watchdog crash
    The controller was started at boot, so with no transceiver (or a floating
    RX pin) it received continuous garbage; twai_receive never blocked and the
    priority-6 can_rx task starved IDLE0, tripping the task watchdog ~5s after
    boot, before any recording.
    - can_init() installs the driver but no longer calls twai_start().
    - writer_start_recording() starts TWAI (and only then sets s_recording, so
    the RX task never receives on a stopped controller); bails out cleanly if
    the start fails.
    - writer_stop_recording() stops TWAI after clearing s_recording.
    - can_rx_task() sleeps 20ms while idle and uses a 100ms twai_receive
    timeou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
    [logger_main.c]
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2026-07-01 logger: select ST7789 LCD controller for WROVER-KIT v4.1
    The BSP defaults to ILI9341, but the v4.1 kit ships the ST7789 panel;
    the wrong controller drives it with the wrong init sequence (garbage /
    1px vertical stripes). Pin CONFIG_BSP_LCD_ST7789 in the defaults.
    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
2026-07-01 logger: drive the LCD with the real ILI9341 driver
    The ESP-WROVER-KIT v4.1 panel is an ILI9341, but the esp_wrover_kit BSP
    only ships the ST7789 driver — its "ILI9341" menuconfig option merely
    flips colour order/mirror and still calls esp_lcd_new_panel_st7789. That
    mismatch left the panel showing garbage / fine vertical stripes.
    Bring the LCD up ourselves in display_init.c using the real
    espressif/esp_lcd_ili9341 driver + esp_lvgl_port, reusing the BSP pin
    macros and backlight helpers. The BSP still owns the microSD and button.
    bsp_display_lock/unlock keep working (they wrap the global lvgl_port lock
    we initialise here). Drops the now-irrelevant BSP LCD-type default.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
    [logger_main.c]
2026-07-01 logger: instrument display bring-up (direct-draw self-test + logging)
    Stop guessing at the blank/striped panel. Add a direct-to-panel self-test
    that fills the screen with solid R/G/B/W/K bars via esp_lcd_panel_draw_bitmap
    (no LVGL involved), plus verbose logging of the resolved LCD pins, the SPI
    bus, the panel IO/handle, and each init step. Enable the ILI9341 driver's
    own DEBUG logs so its init command sequence is visible on the console.
    This isolates the failure: solid colour bars => SPI + panel + driver work
    and the problem is in the LVGL layer; still stripes => the problem is below
    LVGL (SPI/panel/format/wiring). Toggle with LOGGER_DISPLAY_SELFTEST.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
2026-07-02 logger: add an LCD status console (ST7789, no LVGL/BSP)
    The only other status indicator on the WROVER-KIT is the onboard RGB LED,
    and two of its three legs (IO2/IO4) are shared with the microSD's 4-bit
    SDMMC bus, leaving just the red channel -- not enough to show status. Bring
    the LCD back instead, this time correctly: the earlier attempt (removed in
    bc5a73e) assumed the panel was an ILI9341 that the esp_wrover_kit BSP
    couldn't drive, but the board is confirmed v4.1 and the BSP's own driver
    always issues ST7789 init commands regardless of its "ILI9341" Kconfig
    option (which only flips a mirror flag) -- so that direction was chasing
    the wrong controller. The one attempt that used the BSP's re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
    [logger_main.c]
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2026-07-02 logger: fix LCD color inversion default, document GPIO21/SD DC conflict
    Hardware bring-up on a WROVER-KIT v4.1: with the microSD card removed the
    panel renders correctly, but every color came out as its exact complement
    (the RGBWK self-test cycled CMYKW, and log text was black-on-white instead
    of the intended white-on-black) -- textbook symptom of an unwanted color
    invert. LOGGER_LCD_INVERT_COLOR defaulted to y on the unverified assumption
    that this panel needed it; flip the default to n now that hardware confirms
    otherwise. Still Kconfig-toggleable for other panels.
    Also document a second, more serious finding: with a card inserted the LCD
    never updates at all (stuck on its post-reset colo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
2026-07-02 logger: drop the LCD console -- DC/GPIO21 conflicts with the SD card
    Hardware bring-up confirmed the LCD is a dead end here, not a driver bug:
    its DC (data/command) line is hardwired to GPIO21, which the WROVER-KIT
    also routes to the microSD socket's card-detect switch. A from-scratch
    ST7789/ILI9341 console (no LVGL/BSP, direct esp_lcd driver, this session's
    work) rendered correctly with the card removed but never updated at all
    with a card inserted -- the socket's CD contact contends with DC the whole
    time a card is present. The microSD is the entire point of this device, and
    DC has no alternate pin to move to (it's soldered, not header-routed), so
    the LCD can't coexist with actual logging.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
    [logger_main.c]
2026-07-02 logger: add a status indicator on the onboard red LED (GPIO0)
    With the LCD ruled out (DC/GPIO21 contends with the microSD card-detect
    switch) and green/blue tied up as the SD bus's D0/D1, the red LED die on
    GPIO0 is the only indicator left. It's also the boot-mode strap pin, but
    that's sampled once, fresh, at reset before any of our code runs, so
    driving it as a plain output afterward is safe -- confirmed by the fact
    that it's exactly how Espressif's own board wires this LED (bsp_led_t:
    BSP_LED_RED = GPIO_NUM_0, driven directly with no special handling in
    their BSP).
    status_led.c owns the GPIO and runs a small background task rendering
    whichever of three states is current: idle (slow heartb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
    [logger_main.c, status_led.c]
2026-07-03 logger: fix frame drops by batching SD writes with setvbuf
    At motorcycle bus loads (~1490 frames/s), the writer was capped near
    ~400 frames/s: the default ~128 B stdio buffer flushed an SD block write
    every few frames, so the RX-to-writer queue overflowed and ~70% of
    frames were dropped (e.g. wheel-speed ID 0x102 captured at 22 Hz instead
    of 100 Hz).
    - setvbuf the .trc stream with a 32 KB fully-buffered block so fwrite
    batches into full SD clusters; buffer is allocated on open and freed on
    both the twai_start-failure and normal-stop paths. Falls back to the
    default buffer (with a warning) if the allocation fails.
    - Grow the TWAI RX queue 32 -> 128 (~85 ms of slack) so a brief SD stall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
    [logger_main.c]
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2026-07-04 ci: restore brake_light esp32 build row dropped in merge
    The merge that added the logger firmware left the second brake_light matrix
    entry without a `target:`, so brake_light was no longer built for the classic
    ESP32. Restore `target: esp32`.
    Claude-Session: https://claude.ai/code/session_01Kw38DLqEoFwjJHvfHTeCc8
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2026-07-04 Fix -Werror=format build failures in net/link CLI printf calls
    CI failed on all four transmitter/brake_light matrix jobs: this
    toolchain's uint32_t is `long unsigned int`, so printf("%u", ...) on
    the uint32_t send/rx counters in cmd_net.c and cmd_link.c tripped
    -Werror=format. Switch those to PRIu32 (uint16_t/uint8_t fields
    elsewhere are fine as %u since they promote to int).
    Claude-Session: https://claude.ai/code/session_01SbxGjeyio95fxd8vm2iq56
2026-07-04 Fix asymmetric pairing race between transmitter and brake_light
    pair start on both boards within the same window was supposed to let
    each discover the other, but whichever board was already broadcasting
    when the second one joined would hear the second board's very first
    announcement almost instantly (bench-proximity radio latency) — often
    before its own next scheduled 200ms broadcast — and immediately went
    silent on discovery. That could leave the second board never hearing a
    single packet back before its own 15s window expired, even though the
    first board paired successfully.
    pairing_start() now keeps broadcasting for a short grace period
    (PAIR_GRACE_SENDS, ~1.6s) after discovering a p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
2026-07-04 tools: fix stuck gauge readouts in trc_viz
    The speed/rpm gauge center numbers are draw_text nodes; their content
    updates via configure_item(text=...), not set_value (a no-op on drawlist
    items), so they were frozen at "0" while the needles moved. Switch to
    configure_item. Also snapshot mid-ride in --selftest so the frame shows
    representative live values.
    [trc_viz.py]
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2026-07-04 tools: fix frozen acceleration + add accel/decel bar
    The derived acceleration was effectively frozen: the wheel-speed frames
    (0x102) arrive at ~100 Hz, so the firmware's 16-deep history ring spans only
    ~150 ms — less than the 200 ms accel window — and the "newest sample >= 200 ms
    old" search almost never succeeds, updating accel only on rare >200 ms frame
    gaps. As a result the brake FSM missed most decelerations. Deepen the ring to
    32 samples (~320 ms) so the window is genuinely spanned every frame; accel now
    updates continuously and the FSM catches braking (on-time 24% -> 41%,
    transitions 12 -> 37). This mirrors a latent firmware bug: can_decode.h's
    SPEED_HIST=16 is too small for its ow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
    [trc_viz.py]
2026-07-04 tools: low-pass the wheel speed before the decel slope calc
    Small aberrations in the raw wheel-speed trace (quantization steps and the
    occasional single-sample glitch) were injecting spurious slope spikes that
    tripped the decel trigger. Add a causal, dt-aware EMA low-pass on the raw
    wheel-speed samples applied *before* the slope estimator (per the DE-09 note
    that the filter is a tunable), leaving the displayed speed untouched.
    Exposed as speed_smooth_ms (default 80 ms) via CLI flag and a live slider; the
    raw per-frame samples are retained so acceleration is re-derived when the
    smoothing changes. On the ride log this cuts FSM transitions 37 -> 29 and
    sub-0.5 s light blips 4 -> 1 while holdin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
    [trc_viz.py]
2026-07-05 Fix transmitter build: use `driver` for TWAI on IDF 5.3
    The transmitter `main` component declared `esp_driver_twai` in
    PRIV_REQUIRES, but that standalone component only exists on ESP-IDF
    >= 5.5. CI builds against release-v5.3, where cmake fails with
    "Failed to resolve component 'esp_driver_twai'".
    The code uses the legacy TWAI API (driver/twai.h), which on 5.3 is
    provided by the umbrella `driver` component. Depend on that instead so
    both the esp32 and esp32c3 transmitter builds configure and compile.
    Claude-Session: https://claude.ai/code/session_012Lk1D9ZrcLBidtkQjuwMM9
2026-07-09 feat: Custom logger hardware
    [logger.kicad_pcb, logger.kicad_sch]
2026-07-09 Kicad updates and ignore
    [logger.kicad_pcb]
2026-07-10 Trace visualizer tool - add throttle position, fix clutch state visualization
    [trc_viz.py]
2026-07-10 Logger documentation and reference materials
    [logger.kicad_sch]
2026-07-17 fix: I/O allocations on logger ESP32-S3
    [bom.csv, designators.csv, logger.kicad_pcb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]
2026-07-18 Logger: Add LEDs, connector silk, layout updates
    [logger.kicad_pcb, logger.kicad_sch]
2026-07-18 Logger: Add UART test pads
    [bom_202607172215.csv, designators.csv, logger.kicad_pcb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]
2026-07-18 Logger: Fix GPIO45 usage
    [logger.kicad_pcb, logger.kicad_sch]
2026-07-18 Logger: Switch to TPS62162DSGR with 1A output rating
    [logger.kicad_pcb, logger.kicad_sch]
2026-07-19 Logger doc updates
    [logger.kicad_sch]
2026-07-19 Remove old production files from logger dir
    [bom.csv, bom_202607172215.csv, designators.csv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]
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2026-07-22 Add brake light LED driver evaluation mini circuit
    [led_drv_eval.kicad_prl.kicad_pcb, led_drv_eval.kicad_prl.kicad_sch]
2026-07-22 First pass at brake light hardware
    [brake_light.kicad_pcb, brake_light.kicad_sch, led_drv_eval.kicad_prl.kicad_pcb]
2026-08-04 Add logger PCB bring-up scratch app and record §1–§4 results
    Bring-up tooling for the logger PCB (ESP32-S3-WROOM-1-N4), plus the
    BRINGUP.md results the tooling produced.
    New: logger/software/bringup/
    - blink/ — scratch app exercising the §0 pin map: status LEDs D6/IO1 and
    D5/IO2 (§4.1) and microSD card-detect DET_A/IO8 (§4.5). The LED pattern
    drives each LED alone before alternating, so it distinguishes "both LEDs
    work" from "the pins are swapped". DET_A is read with the internal pull-up
    disabled so the high state proves R17 rather than the internal pull — an
    internal pull would turn a missing R17 into a false pass.
    - reset_soak.py — §4.3 boot-repeatability soak, 20/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
    [blink_main.c, reset_soak.py]
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
